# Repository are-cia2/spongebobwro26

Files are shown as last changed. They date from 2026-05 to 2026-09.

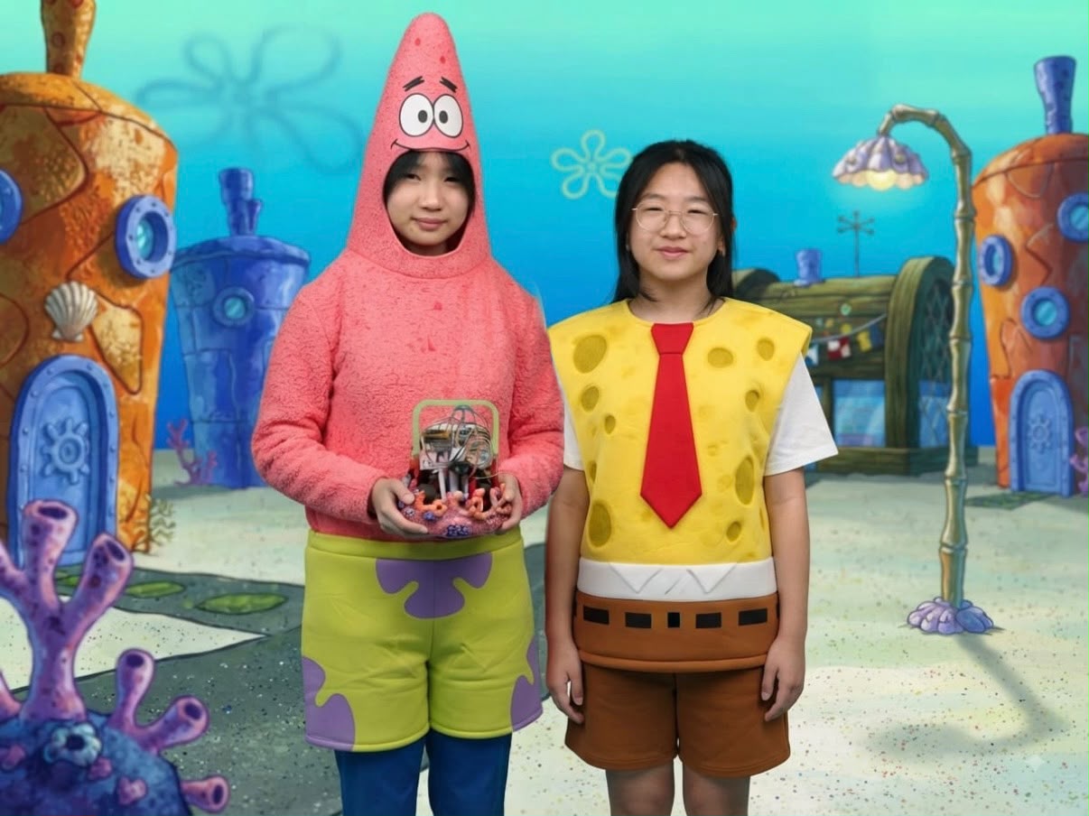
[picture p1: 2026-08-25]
t-photos/funnypic.jpeg

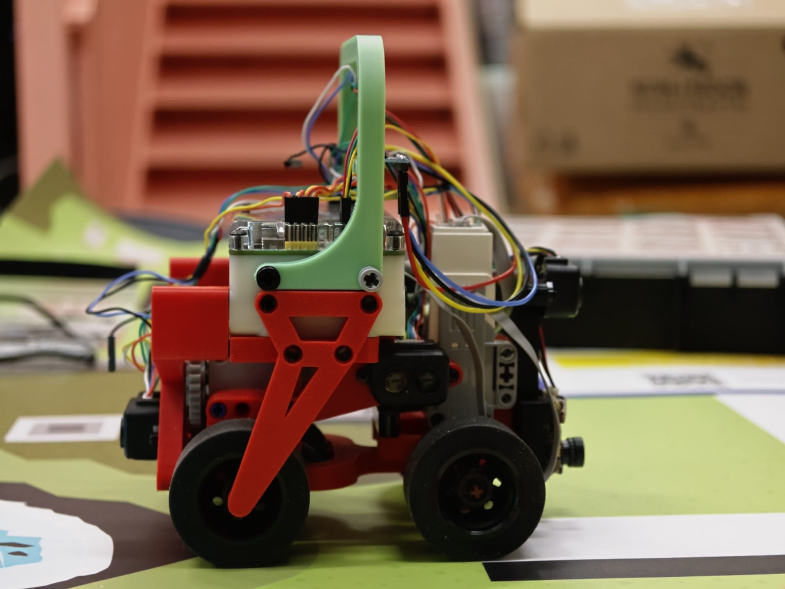
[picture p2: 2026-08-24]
v-photos/rightview.jpeg

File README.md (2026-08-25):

# CORE SPONGEBOB – WRO Future Engineers 2026

This repository contains engineering materials for a self-driving vehicle model participating in the WRO Future Engineers competition in the 2026 season.

## Team
WhatsApp Image 2026-08-23 at 12 37 10 PM

---

## Robot Overview
Our robot was designed with a custom 3D-printed chassis, Ackermann steering geometry, 

Our vehicle is a four-wheeled, car-like autonomous robot built around an EVN Alpha RP2040 controller, a mixed 3D-printed PLA/LEGO-compatible chassis and and a sensor suite optimised for wall tracking and obstacle navigation. One LEGO MINDSTORMS EV3 Medium Motor drives a mechanically linked axle through a gear train and differential. A second EV3 Medium Motor actuates a geared Ackermann steering linkage. The robot uses 40 mm silicone wheels. Four TF-Luna LiDAR sensors point forward, rearward, left, and right. An MPU6500 inertial measurement unit provides relative yaw through the I2Cdevlib Digital Motion Processor (DMP).

For both challenges, the vehicle follows a wall down each straight, detects the open side of each corner, turns to successive 90-degree headings, counts 12 corners as three laps, and brakes when the front and rear ranges indicate that it has returned to its starting section. The software runs sensing on one RP2040 core and navigation/motor control on the other.

## Robot Pictures

| Front View | Left View | Right View |
|---|---|---|
| Front View | Back View | Top View |

| Top View | Bottom View | Back View |
|---|---|---|
| Bottom View | Left View | Right View |

---

## Performance Videos
Open challenge: https://youtu.be/y6kY5s8JME0?si=EC7A0Hvez6JDP7O8

Obstacle challenge: https://youtu.be/tH5Cm9ztciE?si=E40YTndC0-gIS9aX

---

## Mobility & Mechanical Design

For this competition, we custom‑designed our chassis in Fusion 360 and manufactured components using FFF 3D printing with PLA. The platform integrates off‑the‑shelf electronics, including LEGO MINDSTORMS EV3 medium motors and a custom sensor suite: four TF‑Luna LiDAR sensors for ranging, an MPU6500 6‑DOF IMU for heading estimation, and an OpenMV Cam H7 (AE3) for visual navigation. Power is supplied by two 18650 cells in series, regulated through DRV8833 motor‑driver circuitry.

The vehicle combines:
- EVN ALPHA as the main single‑board microcontroller  
- LEGO MINDSTORMS EV3 medium motors for drive and steering  
- Four Benewake TF‑Luna time‑of‑flight sensors for left, right, front, and rear ranging  
- An MPU6500 IMU with DMP for yaw estimation  
- An OpenMV AE3 camera for red/green traffic‑sign detection  
- Two 18650 cells connected in series  
- DRV8833 motor‑driver circuitry  
- [Custom printed chassis, sensor mounts, motor mounts, steering linkage, braces, and gear components](https://github.com/are-cia2/spongebobwro26/tree/main/models)

### Chasis
We designed a custom 3D‑printed chassis instead of using modular building sets because the competition requires a compact steering vehicle with geometry that cannot be optimised using fixed modules. Autodesk Fusion 360 allowed us to integrate the chassis, mounts, gear interfaces, and steering linkage into one coordinated system. This ensured that every structural element was aligned with the drive and steering requirements. FFF printing with PLA reduced cost and enabled rapid iteration, allowing us to test three chassis prototypes before finalising the design.

The chassis features a narrow front profile and short wheelbase to maximise steering angle and reduce turning radius. The EVN ALPHA controller is secured in a cross‑braced mount, while the back frame supports the gear train and rear sensor. Side braces connect the rear wheel area to the controller mount to minimise flex and preserve alignment during high‑torque manoeuvres.

### Torque-Speed Trade-Off 
We explicitly calculated torque and speed trade‑offs by testing three gear ratios (1:1, 1:2, and 1:3). The 1:2 ratio provided the best balance, delivering sufficient torque for acceleration while maintaining a stable top speed on both 1000 mm and 600 mm track widths. Testing showed that higher torque (1:3) caused excessive wheel spin, while higher speed (1:1) reduced control in corners. Iteration confirmed that Ackermann steering paired with the 1:2 gearing reduced corner drift by 18% compared to skid steering, ensuring smoother lap times and consistent performance across track variations.

### Controller
**[EVN Alpha](https://github.com/are-cia2/spongebobwro26/blob/main/schemes/evnFrontpins.svg) (16 I2C channels, USB-C for code upload)**

We decided to make use of the EVN Alpha to control the robot. Compared to the LEGO Mindstorms EV3 and NXT controllers, the EVN Alpha has 64 holes on 5 sides of the controller, compared to 32 holes on 3 sides of the other controllers, making it much easier to mount other parts on the EVN Alpha. Furthermore, the EVN Alpha is also much more compact, allowing the robot’s movements to be much more precise and accurate. The EVN Alpha also features a USB-C Port that is used to charge the batteries and download code, which is much more convenient compared to the EV3 or other NXT Controllers. Lastly, this controller has a total of 16 I2C channels, which eliminates the 4-port constraint of other controllers like the EV3 brick. 

### Motors
**2 × LEGO EV3 Medium [Motors](https://github.com/are-cia2/spongebobwro26/blob/main/schemes/evnBackpins.svg) (drive + steering)**

Our robot uses 2 LEGO MINDSTORMS EV3 medium motors due to their lightweight, compact form factor, and high speed compared to EV3 large motors and NXT motors. 

*Drive Mechanism and Differential*

One LEGO MINDSTORMS EV3 Medium Motor drives the wheel axle through a multi-stage
gear train and a mechanical differential to transfer power to the desired wheel location while balancing speed and torque. The differential lets the inside and outside wheels rotate at different speeds in corners while remaining powered from one motor, which satisfies the WRO prohibition on independent differential drive. The vehicle rolls on four nominally 40 mm silicone wheels; their loaded diameter still needs a calliper measurement for the final distance calibration.

The current software contains this output-speed ratio:

```text
wheel revolutions / motor revolution = (40 / 24) / 1.4 / 1.67
                                     = approximately 0.713
```

This means the ideal torque multiplication is the reciprocal:

```text
ideal torque multiplication = 1 / 0.713 = approximately 1.403
```

To shorten the wheelbase as much as possible, the long medium motor is mounted directly above the main drive assembly. The drivetrain comprises three distinct reduction stages:
- First Stage (40:24): A big-to-small gear configuration directly from the medium motor designed to compact the motor placement and optimise the overall layout.
- Second Stage (20:28): A small-to-big setup driving the differential gear, using a 20-tooth bevel pinion gear to drive a 28-tooth crown wheel on the rotating cage, enabling right-angle torque transmission.
- Third Stage (12:20): A small-to-big stage providing the final speed reduction to the wheels. Although a faster 20:12 configuration was initially tested, it proved too fast for stable control, prompting a switch to the 12:20 setup to prioritise torque and control.

*Steering Mechanism*
The steering actuator is a LEGO MINDSTORMS EV3 Medium Motor on EVN motor port 3.
Encoder channels on GPIO 14 and 15 provide position feedback. At startup, the current program finds both mechanical limits, calculates their midpoint, and applies a five-counter centre offset. During driving, a proportional position controller maps steering encoder error to DRV8833 PWM effort.

```text
  targetPosition = constrain(targetPosition, rightAngle - 5, leftAngle + 5);
  int positionError = pulseCount - targetPosition;
  int pwmRun = constrain(positionError * 22, -255, 255);
```

The geared linkage uses Ackermann steering geometry so the inner wheel can turn
through a larger angle than the outer wheel. This reduces tire scrub compared
with parallel steering. Current scaled-setup trials suggest an approximately
150 mm turning radius, but this is an estimate rather than a dimensioned final
measurement.

### Sensors

**4 × [TF-Luna](https://github.com/are-cia2/spongebobwro26/blob/main/schemes/TFLunapins.jpeg) LiDAR (front, rear, left, right)**

This sensor is a Time of Flight (TOF) distance measurement sensor. We chose to use this sensor because it is able to measure object distance accurately by measuring how long the light takes to bounce back to the sensor. The code corrects line-of-sight range to estimated perpendicular wall distance:

$$
d_{perpendicular} = d_{raw}\cos(\Delta\psi)
$$
where $\Delta\psi$ is yaw relative to the nearest cardinal field heading. This
assumes a planar axis-aligned wall and is intentionally not trusted when a beam
looks through an open corner.
    
**1 x [MPU6050](https://github.com/are-cia2/spongebobwro26/blob/main/schemes/MPU6050pins.jpeg) IMU (yaw estimation)**

The IMU mount began as a carrying handle but was repurposed to hold the IMU level and away from motor heat, preserving sensor accuracy. The front sensor mount fixes the camera and forward LiDAR in a repeatable geometry, while side and rear LiDAR mounts elevate the sensors to reduce floor reflections and maintain clear views of the field walls. This placement strategy was iterated three times, with final mounting heights chosen to maximise detection reliability at the sensors’ 3‑meter range.

**1 × [OpenMV AE3 camera](https://github.com/are-cia2/spongebobwro26/blob/main/schemes/OpenMVae3pins.jpeg) (traffic sign detection)**

The OpenMV AE3 allows for a long-range vision strategy while significantly elevating performance. Equipped with dual hardware Neural Processing Units (NPUs) and a 1 MP colour global shutter sensor, the AE3 processes machine-learning detection models with minimal latency and captures crystal-clear frames without motion blur while driving. Combined with low power consumption and onboard Time-of-Flight ranging, the OpenMV AE3 is more than sufficient for rapidly classifying visual targets and enabling swift, accurate navigation decisions during dynamic runs.

#### Electrical Architecture and Wiring

```mermaid
flowchart TD
   BAT[2S Molicel P26A: 7.2 V nominal, 8.4 V full, 2.6 Ah] --> PROTECT[Fuse or protection: TBD]
    PROTECT --> SWITCH[Main power switch]
    SWITCH --> EVN[EVN Alpha]
    EVN --> M1[Motor port 1: drive motor]
    EVN --> M3[Motor port 3: steering motor]
    EVN --> MUX0[I2C mux bank Wire: ports 1-8]
    MUX0 --> P1[Port 1: MPU6500]
    MUX0 --> P2[Port 2: rear TF-Luna]
    MUX0 --> P3[Port 3: front TF-Luna]
    MUX0 --> P4[Port 4: left TF-Luna]
    MUX0 --> P5[Port 5: right TF-Luna]
```

### Power
**2 × 18650 cells in series (8.4 V max), regulators for 3.3 V and 5 V rails** 

They are connected in series to provide the EVN ALPHA with 8.4v and are rated for 4.2v when fully charged. The motors run off unregulated battery power, consuming up to 780mA each at stall. There are 2 on-board regulators. The 3.3v regulator powers most of the system and is able to supply 3A. The current consumption of our 3.3V peripherals is under 1A. The 5V regulator only supplies the 5V rail and provides up to 3A. The only sensors we have attached to the 5V rail are the 2 Benewake sensors. While ranging, each sensor draws up to 600mA in a short pulse. This means that we are also well within the current capabilities of the regulator. 

The cells we use are the Molicel P26A, featuring a maximum discharge current of 35A. At maximum load, our robot uses less than 2A with the maximum contribution from the 2 medium motors. With a rated capacity of 2.6Ah, it can easily last more than an hour of continuous operation.

---
## System Architecture

```mermaid
flowchart LR
    Battery[Battery and protection] --> Alpha[EVN Alpha RP2040]
    Alpha --> DriverA[Motor port 1 H-bridge]
    Alpha --> DriverS[Motor port 3 H-bridge]
    DriverA --> Drive[Medium drive motor]
    Drive --> Gearbox[Drive gear train]
    Gearbox --> Diff[Differential and drive axle]
    DriverS --> Steering[Medium steering motor]
    Steering --> SteerGear[Steering gear train and linkage]
    DriveEncoder[Drive encoder] --> Core0[Core 0: navigation and control]
    SteeringEncoder[Steering encoder] --> Core0
    StartButton[One start button] --> Core0
    MPU[MPU6500 yaw] --> Core1[Core 1: sensor service]
    Front[Front TF-Luna] --> Core1
    Rear[Rear TF-Luna] --> Core1
    Left[Left TF-Luna] --> Core1
    Right[Right TF-Luna] --> Core1
    Core1 -->|yaw, ranges, validity| Core0
    Core0 --> DriverA
    Core0 --> DriverS
```

The main subsystem interfaces are deliberately narrow. Core 1 is the only core that performs I2C transactions. It publishes scalar yaw and range values plus validity flags. Core 0 consumes those values, evaluates the navigation state machine, and drives both motors. This prevents motor timing from being coupled directly to slow I2C register reads and avoids simultaneous I2C use by both cores. 

## Code Structure

### Setup
The setup procedure is a calibration-and-initialisation routine: the code first configures the encoder interrupts for both steering channels, initialises the motor pins, and then sweeps the steering mechanism to find the left and right mechanical bounds. It records those positions as leftAngle and rightAngle, calculates the centre zeroPosition, and waits for the user button/input before starting the run. After that, it launches the sensor/IMU core (Core 1), allowing the main loop to use live yaw and distance data from the MPU and ToF sensors while continuously steering toward the required wall-tracking and turning states. In other words, the robot is first mechanically centred and calibrated, then the sensing system is started, and only after the IMU is valid does the state machine begin.

### Core 1 (Sensors)

```mermaid
stateDiagram-v2 
  [*] --> INITIALISE 
  INITIALISE --> CALIBRATE: calibration required 
  INITIALISE --> LOADOFFSETS: calibration saved 
  CALIBRATE --> IMU LOADOFFSETS --> IMU 
  IMU --> READSENSORS READSENSORS --> 
  READSENSORS: update yaw + distance sensors 
  READSENSORS --> CAMERA: Obstacle Challenge 
  CAMERA --> READSENSORS: colour detected / no colour 
  READSENSORS --> ROBOTCONTROL 
  ROBOTCONTROL --> READSENSORS
```

### [Open Challenge](https://github.com/are-cia2/spongebobwro26/tree/main/src/wro26open) State Machine

```mermaid
stateDiagram-v2
    [*] --> START
    START --> FIRSTWALL: yaw and four ranges ready
    FIRSTWALL --> BASICOVERSHOOT: front near and one side open
    BASICOVERSHOOT --> TURNRIGHT: CW entry distance reached
    BASICOVERSHOOT --> TURNLEFT: CCW entry distance reached
    TURNRIGHT --> FINDWALL: target 90-degree heading reached
    TURNLEFT --> FINDWALL: target 90-degree heading reached
    FINDWALL --> WALLTRACK: inside wall reacquired after delay
    WALLTRACK --> BASICOVERSHOOT: corner 1 through 11
    WALLTRACK --> OVERSHOOT: approach to corner 12
    OVERSHOOT --> TURNRIGHT: final CW entry reached
    OVERSHOOT --> TURNLEFT: final CCW entry reached
    TURNRIGHT --> LASTWALL: final turn complete
    TURNLEFT --> LASTWALL: final turn complete
    LASTWALL --> STOP: startup front/rear pose crossed
    STOP --> STOP
```

### [Obstacle](https://github.com/are-cia2/spongebobwro26/tree/main/src/wro26obstacle) Challenge State Machine

```mermaid
stateDiagram-v2 
  [*] --> START 
  START --> FIRSTWALL: sensors valid and starting wall selected 
  FIRSTWALL --> LEFTOBSTACLE: green obstacle detected
  FIRSTWALL --> RIGHTOBSTACLE: red obstacle detected FIRSTWALL --> STOP: front detected + corner direction identified 
  LEFTOBSTACLE --> FIRSTWALL: obstacle passed 
  RIGHTOBSTACLE --> FIRSTWALL: obstacle passed 
  FIRSTWALL --> BASICOVERSHOOT: corner detected 
  BASICOVERSHOOT --> TURNRIGHT: CW distance reached 
  BASICOVERSHOOT --> TURNLEFT: CCW distance reached 
  TURNRIGHT --> FINDWALL: 90-degree heading reached 
  TURNLEFT --> FINDWALL: 90-degree heading reached 
  FINDWALL --> RIGHTOBSTACLE: wall reacquired after delay 
  FINDWALL --> LEFTOBSTACLE: obstacle detected 
  RIGHTOBSTACLE --> FINDWALL: obstacle passed 
  LEFTOBSTACLE --> FINDWALL: obstacle passed 
  FINDWALL --> WALLTRACK: wall reacquired 
  WALLTRACK --> LEFTOBSTACLE: obstacle detected 
  WALLTRACK --> RIGHTOBSTACLE: obstacle detected 
  WALLTRACK --> BASICOVERSHOOT: normal corner detected 
  WALLTRACK --> OVERSHOOT: final corner detected 
  BASICOVERSHOOT --> TURNRIGHT: CW
  BASICOVERSHOOT --> TURNLEFT: CCW
  OVERSHOOT --> TURNRIGHT: final CW distance reached 
  OVERSHOOT --> TURNLEFT: final CCW distance reached 
  TURNRIGHT --> LASTWALL: final turn complete 
  TURNLEFT --> LASTWALL: final turn complete
  LASTWALL --> LEFTOBSTACLE: obstacle detected 
  LASTWALL --> RIGHTOBSTACLE: obstacle detected 
  LASTWALL --> STOP: starting position reached
  STOP --> STOP
```
#### [Obstacle Detection Camera Code](https://github.com/are-cia2/spongebobwro26/tree/main/src/wro2026camera) on OpenMV:

The obstacle detection uses the OpenMV AE3 camera to detect red and green blobs in each frame, threshold them by colour, and identify the largest matching blob. It then checks the blob’s orientation and size, and if a valid marker is seen for long enough (based on clock.fps()) and is large enough (height of blob > certain value), it sends a command over UART to the robot indicating whether the obstacle is on the left or right side, using messages like “a”, “b”, “c”, or “d” to signal left green, right green, left red, and right red respectively. This acts as the robot’s external obstacle-awareness layer, allowing the main code to react to colored markers by changing its state in the state machine.

## Testing and Tuning Methods

Our testing and tuning process focuses on changing one independent variable at a time while keeping the test layout and other conditions constant. This allows us to identify which changes actually improve the robot’s performance rather than attributing improvements to multiple changes at once. For each test, we record raw sensor and control data and use a predefined metric, such as completion time, positional accuracy, or number of contacts, to determine whether a change is an improvement. Constants are accepted only after being supported by a specific test record, rather than simply because they appeared to “work better.”

Testing is carried out on our scaled-down test setup, which has a 90 cm × 90 cm middle section and is reasonably close to the dimensions of the actual field. During recent testing, complete Open Challenge runs were observed in under 50 seconds in both clockwise and counter-clockwise directions. We also did not observe noticeable yaw drift or drive-distance errors during these runs. These results suggest that the current tuning is promising, but visual observation alone cannot confirm that the robot has zero error or that the results would be identical on the full regulation field.

To make our conclusions more reliable, further testing will involve recording the number of runs, individual completion times, contacts, finish outcomes, IMU data, and encoder distance compared with physical tape measurements. These records will allow us to calculate meaningful values such as average completion time, error bounds, yaw drift, and success rate. This provides a more systematic basis for selecting and justifying our final constants and ensures that our tuning decisions are supported by measurable evidence.

### Testing Results

| Run | Challenge Type | Direction | Completion Time (s) | Contacts | Heading Accuracy | End Distance from Start (cm) |
|-----|---|---|---|---|---|---|
| 1 | Open | CW | 43.2 | 0 | ±1° | 6 |
| 2 | Open | CCW | 44.1 | 0 | ±2° | 5 |
| 3 | Obstacle | CW | 52.4 | 0 | ±2° | 7 |
| 4 | Obstacle | CCW | 53.0 | 0 | ±1° | 4 |

**Average completion time (Open Challenge):** 49.4s  
**Average completion time (Obstacle Challenge):** 52.7s  
**Contacts:** 0 (all runs successful)  
**Heading accuracy:** consistently within ±2° tolerance  
**End distance from start:** within 5–7 cm (inside threshold)

## Bill of Materials (Core Components)

| Component | Qty | Price (USD) |
|---|-----|---|
| TF-Luna LiDAR | 4 | $27.05 ea |
| OpenMV AE3 Camera  | 1 | $65.00 |
| MPU6050 IMU | 1 | $2.94 |
| EVN Alpha | 1 | $128.00 |
| **Total** | | **$304.14** |

## Upload Process

1. **Code Development**
   - EVN Alpha code written in C++.
   - OpenMV IDE used for AE3 camera scripts written in MicroPython.
   - Fusion 360 for CAD → exported STL → 3D print.

2. **Compilation**
   - EVN Alpha: Code compiled and uploaded via USB-C.
   - OpenMV AE3: Scripts uploaded via OpenMV IDE via USB-C.

3. **Upload**
   - Connect EVN Alpha via USB-C.
   - Flash firmware and upload code using the provided toolchain.
   - Camera scripts deployed separately.
   - 
---

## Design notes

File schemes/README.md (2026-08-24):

Electromechanical diagrams
====

This directory contains several schematic diagrams of the electromechanical components, illustrating the electrical elements used in the vehicle and how they connect to each other.

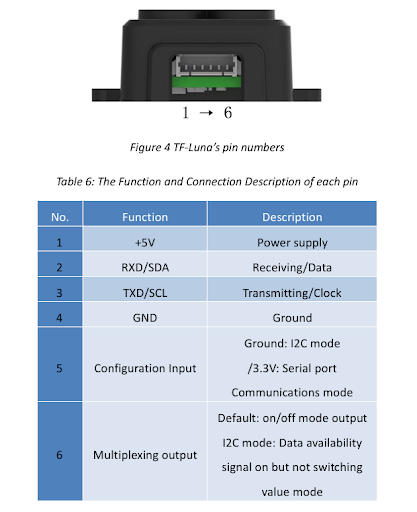
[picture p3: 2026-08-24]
schemes/TFLunapins.jpeg

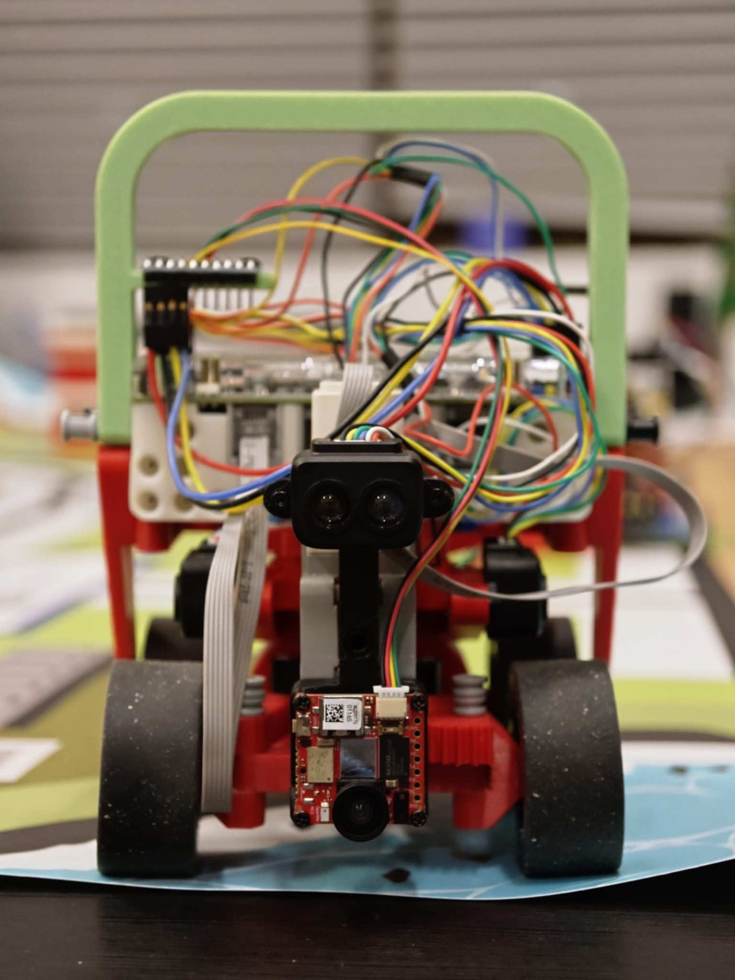
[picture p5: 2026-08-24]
v-photos/frontview.jpeg

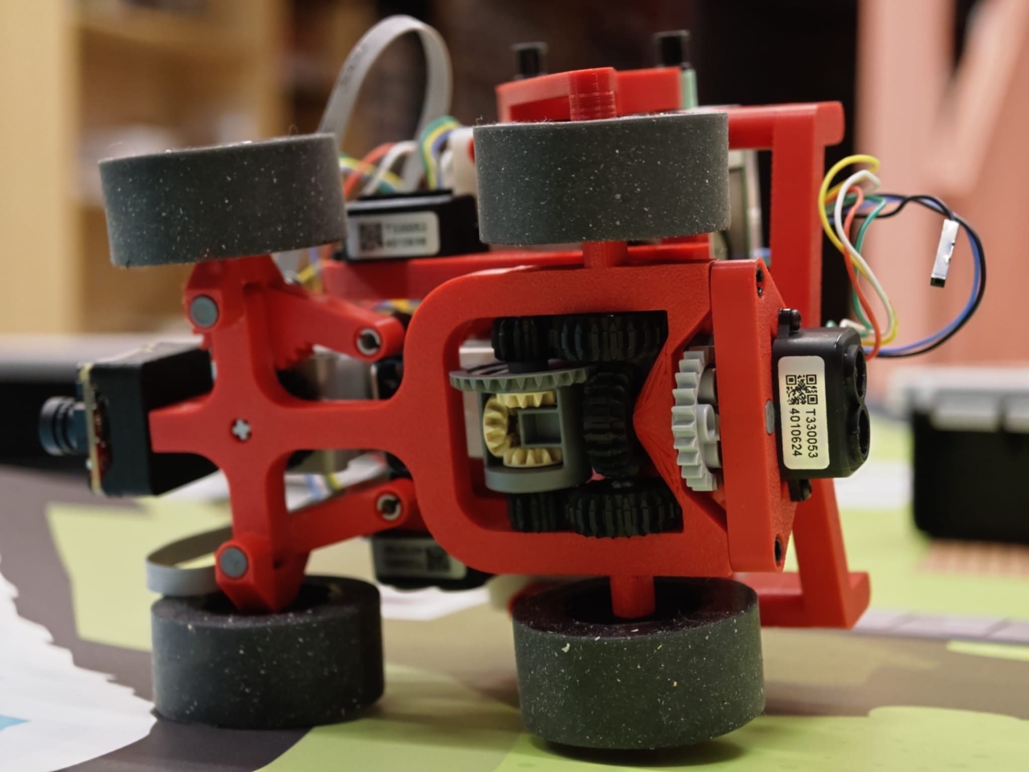
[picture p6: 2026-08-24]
v-photos/bottomview.jpeg

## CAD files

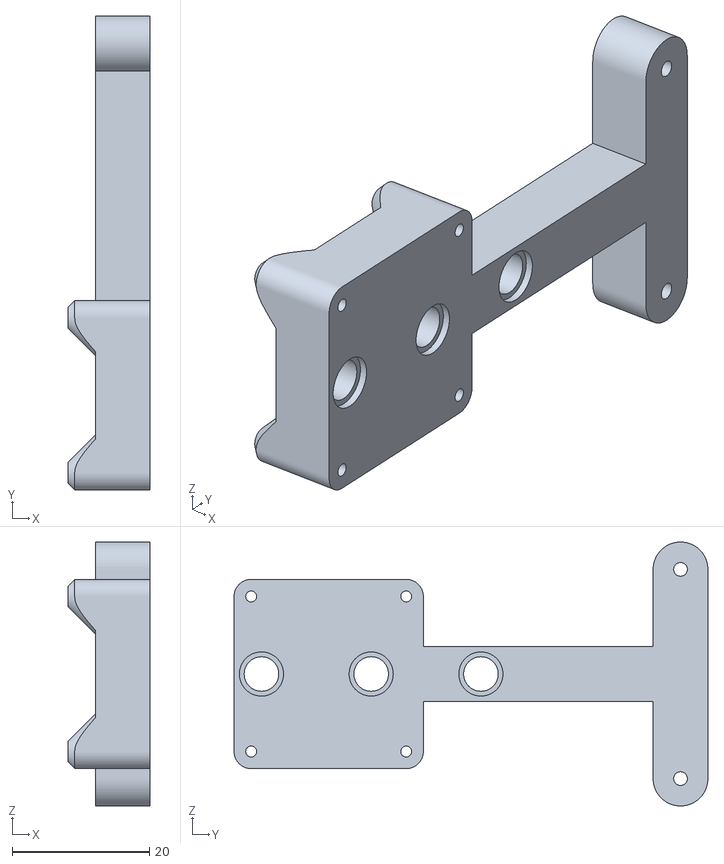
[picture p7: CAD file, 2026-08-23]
models/front mount.stl
12.0 x 69.1 x 38.5

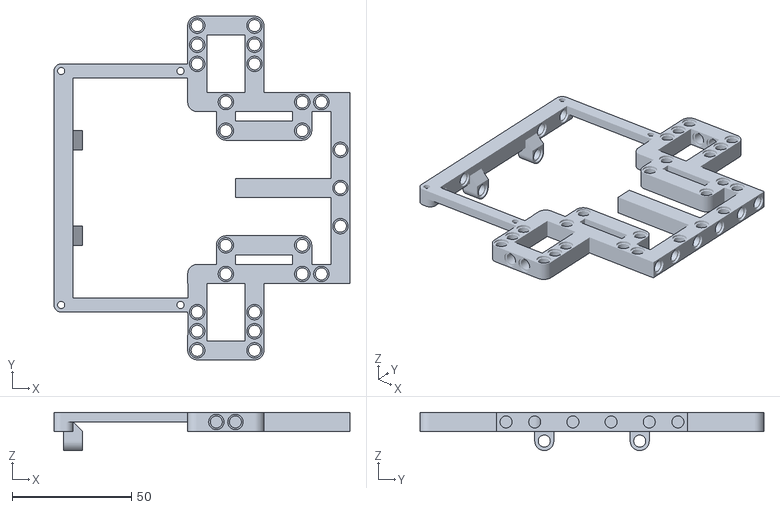
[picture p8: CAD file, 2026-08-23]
models/top frame.stl
124.0 x 144.0 x 16.0

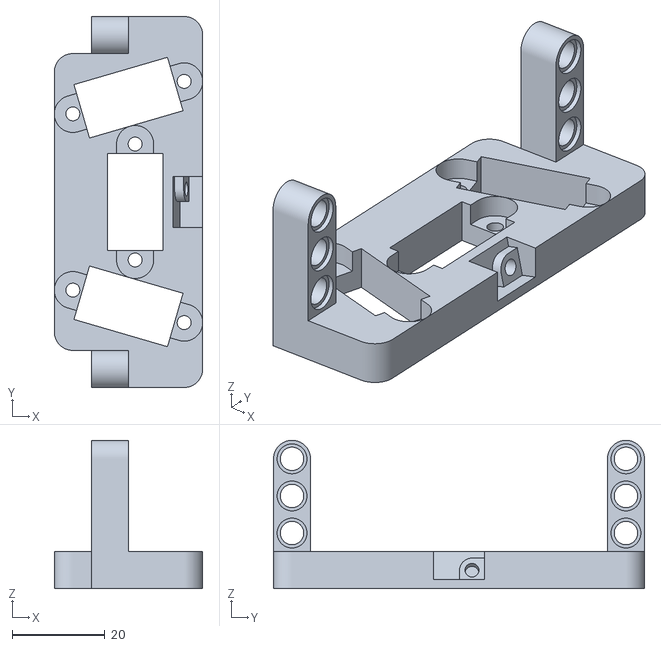
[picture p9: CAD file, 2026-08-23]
models/sensor plate.stl
32.0 x 80.0 x 32.0

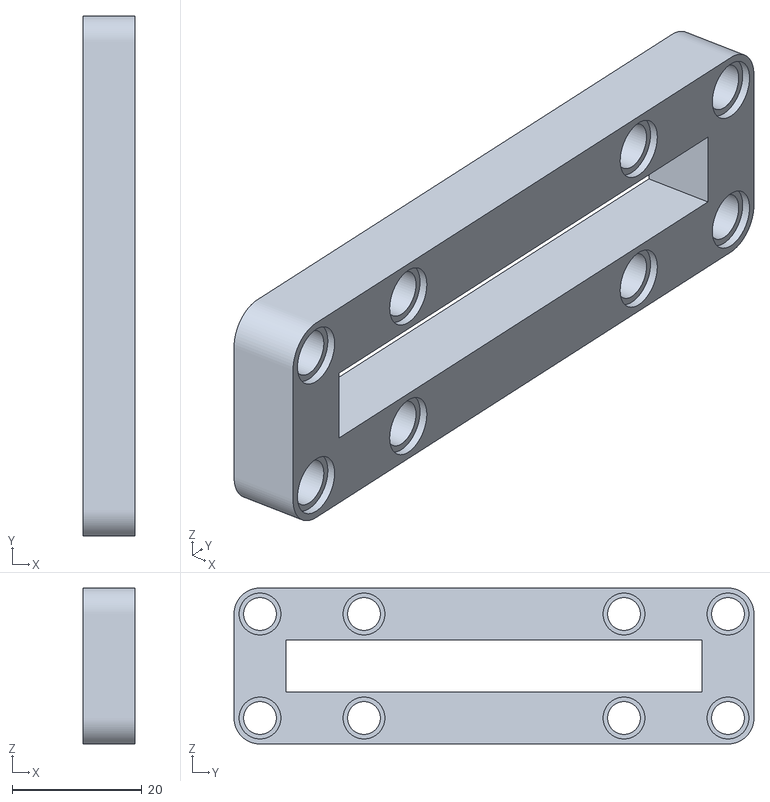
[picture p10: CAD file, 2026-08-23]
models/back frame.stl
8.00 x 80.0 x 24.0

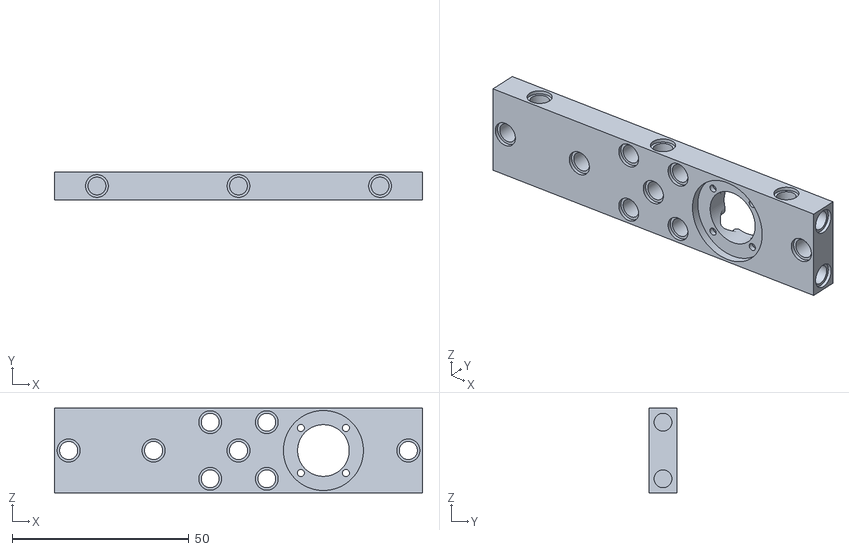
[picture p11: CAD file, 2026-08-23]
models/motor mount.stl
104.0 x 8.00 x 24.0

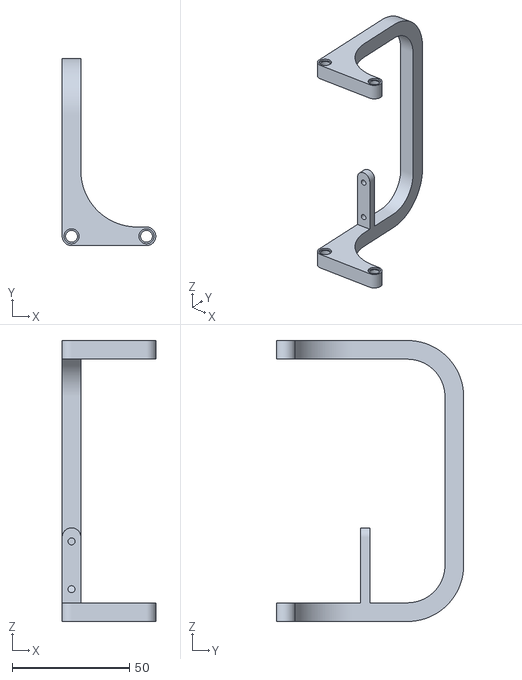
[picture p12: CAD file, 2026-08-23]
models/handle.stl
40.0 x 80.0 x 120.0

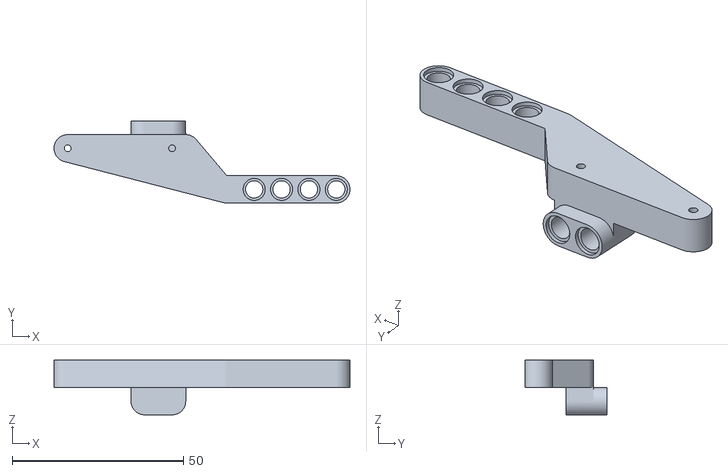
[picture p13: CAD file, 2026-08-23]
models/side sensor mount.stl
86.5 x 24.0 x 16.0

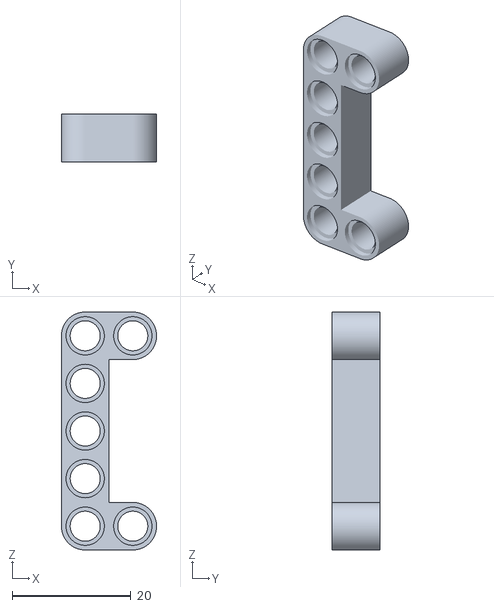
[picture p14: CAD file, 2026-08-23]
models/middle connecting piece.stl
16.0 x 8.00 x 40.0

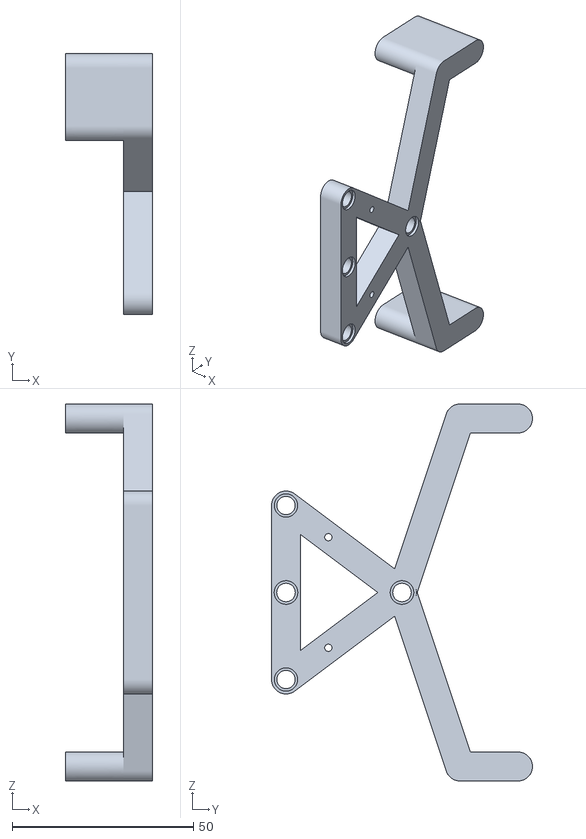
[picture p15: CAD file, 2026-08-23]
models/back brace.stl
24.0 x 72.0 x 104.0

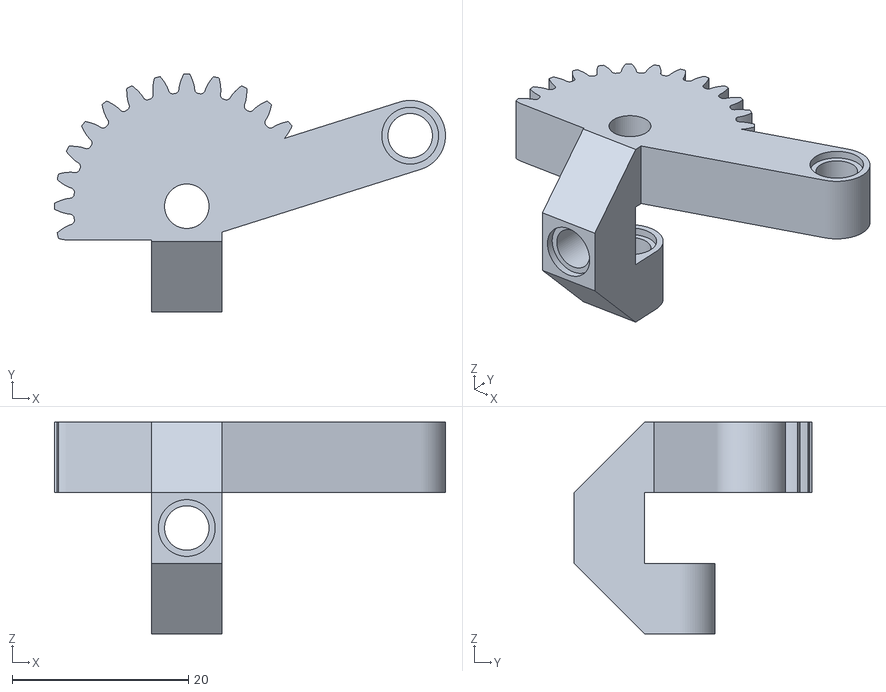
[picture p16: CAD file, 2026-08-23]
models/steering (mirror for sides).stl
44.3 x 27.0 x 24.0

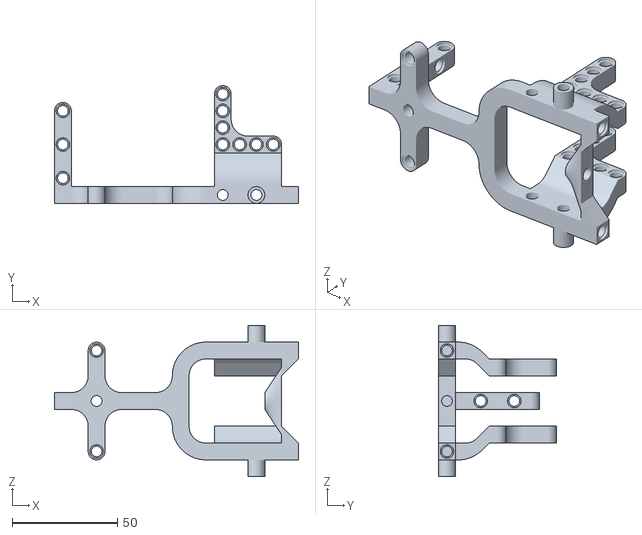
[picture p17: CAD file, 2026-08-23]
models/robot base.stl
116.0 x 56.0 x 72.0

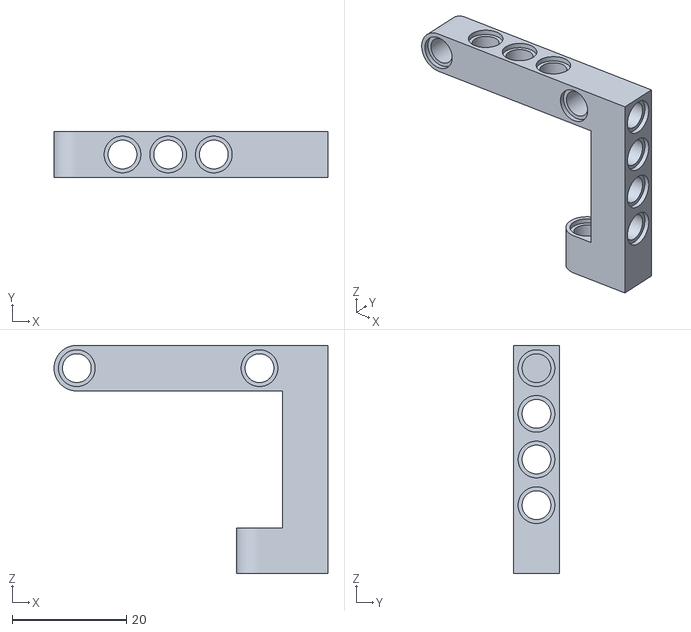
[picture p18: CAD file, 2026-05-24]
models/evn mount.stl
48.0 x 8.00 x 40.0

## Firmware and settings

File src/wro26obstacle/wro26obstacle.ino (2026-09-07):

#include <EVN.h>


#define START 0
#define FIRSTWALL 1
#define TURNLEFT 2
#define TURNRIGHT 3
#define WALLTRACK 4
#define STOP 5
#define PRINT 6
#define FINDWALL 7
#define LASTWALL 8
#define OVERSHOOT 9
#define LEFTOBSTACLE 10
#define RIGHTOBSTACLE 11
#define BASICOVERSHOOT 12
#define REVERSEBACK 13
#define SMALLLEFTTURN 14
#define SMALLRIGHTTURN 15
#define REVERSETURN 16

//to change
#define WALLTRACKDIST 41
#define FRONTTHRES 30
#define BACKTHRES 100
#define CORNERDETECT 88
#define WALLFOUND 60
#define BASICOVERSHOOTDIST 150
#define OVERSHOOTDIST 150
#define TURNTOLERANCE 3
#define DISTTOLERANCE 5
#define WALLAFTOBS 25
#define BIGTURNANGLE 80
#define SMALLTURNANGLE 52

char yippee;

float leftAngle;
float rightAngle;
float zeroPosition;
float leftStartDist;
float rightStartDist;
float frontStartDist;
float backStartDist;
float startDist;
float oriWallDist;
float obstacleDist;
unsigned long long initialTime;
volatile const float gearRatio = (((40.0 / 24.0) / 1.4) / 1.67);
extern volatile bool rangeDataReady;
float leftWallDist;
float rightWallDist;
float lastReverse = -999;

int var = START;
int prevvar = WALLTRACK;
int leftobstaclevar = 0;
int rightobstaclevar = 0;

bool cw = true;
bool startLeft = true;
bool lastturn = false;
int corner = 0;
int frontDistCounter = 0;
int obstacleTurnAngle = 52;
int wallCounter = 0;
int leftCounter = 0;
int rightCounter = 0;


extern volatile float stuffYaw;
extern volatile bool stuffValid;
extern volatile int leftDist;
extern volatile int checkRightDist;
extern volatile int rightDist;
extern volatile int frontDist;
extern volatile int backDist;
extern volatile int snappedHeading;
extern volatile bool lefterror;
extern volatile bool righterror;
extern volatile bool fronterror;
extern volatile bool backerror;

extern volatile bool leftGreen;
extern volatile bool rightGreen;
extern volatile bool leftRed;
extern volatile bool rightRed;

volatile int pulseCount;  // Rotation step count
int SIG_A = 0;            // Pin A output
int SIG_B = 0;            // Pin B output
int lastSIG_A = 0;        // Last state of SIG_A
int lastSIG_B = 0;        // Last state of SIG_B
const int Pin_A = 14;     // Interrupt pin (digital) for A (change your pins here)
const int Pin_B = 15;     // Interrupt pin (digital) for B

void A_CHANGE() {                                 // Interrupt Service Routine (ISR)
  detachInterrupt(digitalPinToInterrupt(Pin_A));  // Important
  SIG_A = digitalRead(Pin_A);                     // Read state of A
  SIG_B = digitalRead(Pin_B);                     // Read state of B

  if ((SIG_B == SIG_A) && (lastSIG_B != SIG_B)) {
    pulseCount--;  // Counter-clockwise rotation
    lastSIG_B = SIG_B;
  }

  else if ((SIG_B != SIG_A) && (lastSIG_B == SIG_B)) {
    pulseCount++;                   // Clockwise rotation
    lastSIG_B = SIG_B > 0 ? 0 : 1;  // Save last state of B
  }
  attachInterrupt(digitalPinToInterrupt(Pin_A), A_CHANGE, CHANGE);
}


volatile int pulseCountback;  // Rotation step count
volatile int initialpulseCountback;
int SIG_Aback = 0;         // Pin A output
int SIG_Bback = 0;         // Pin B output
int lastSIG_Aback = 0;     // Last state of SIG_A
int lastSIG_Bback = 0;     // Last state of SIG_B
const int Pin_Aback = 19;  // Interrupt pin (digital) for A (change your pins here)
const int Pin_Bback = 18;  // Interrupt pin (digital) for B

void A_CHANGEBACK() {                                 // Interrupt Service Routine (ISR)
  detachInterrupt(digitalPinToInterrupt(Pin_Aback));  // Important
  SIG_Aback = digitalRead(Pin_Aback);                 // Read state of A
  SIG_Bback = digitalRead(Pin_Bback);                 // Read state of B

  if ((SIG_Bback == SIG_Aback) && (lastSIG_Bback != SIG_Bback)) {
    pulseCountback--;  // Counter-clockwise rotation
    lastSIG_Bback = SIG_Bback;
  }

  else if ((SIG_Bback != SIG_Aback) && (lastSIG_Bback == SIG_Bback)) {
    pulseCountback++;                       // Clockwise rotation
    lastSIG_Bback = SIG_Bback > 0 ? 0 : 1;  // Save last state of B
  }
  attachInterrupt(digitalPinToInterrupt(Pin_Aback), A_CHANGEBACK, CHANGE);
}


void runPosition(int targetPosition) {
  targetPosition = constrain(targetPosition, rightAngle - 5, leftAngle + 5);
  int positionError = pulseCount - targetPosition;  //(headingError * 5.0) - (steer.getPosition() - STEER_CENTER);
  //Serial.println(positionError);
  int pwmRun = constrain(positionError * 22, -255, 255);
  //Serial.println(pwmRun);
  if (positionError > 0) {
    // turn cw
    digitalWrite(23, HIGH);
    analogWrite(22, 255 - pwmRun);
  } else {
    //turn ccw
    digitalWrite(22, HIGH);
    analogWrite(23, 255 + pwmRun);
  }
}

volatile bool core0_ready = false;
volatile bool core1_ready = false;
int steerRightBound = 0;
int steerLeftBound = 0;

int steerOffset = 5;

void setup() {
  Serial2.begin(115200);

  SIG_Bback = digitalRead(Pin_Bback);  // Current state of B
  SIG_Aback = SIG_Bback > 0 ? 0 : 1;   // Let them be different
  // Attach iterrupt for state change, not rising or falling edges
  attachInterrupt(digitalPinToInterrupt(Pin_Aback), A_CHANGEBACK, CHANGE);

  pinMode(28, OUTPUT);
  pinMode(29, OUTPUT);  // M1

  SIG_B = digitalRead(Pin_B);  // Current state of B
  SIG_A = SIG_B > 0 ? 0 : 1;   // Let them be different
  // Attach iterrupt for state change, not rising or falling edges
  attachInterrupt(digitalPinToInterrupt(Pin_A), A_CHANGE, CHANGE);

  pinMode(23, OUTPUT);
  pinMode(22, OUTPUT);  //M3
  digitalWrite(22, LOW);
  digitalWrite(23, HIGH);
  delay(1000);
  int currPosition = 0;
  int prevPosition = 999;
  while (true) {
    currPosition = pulseCount;
    if (currPosition == prevPosition) {
      break;
    }
    prevPosition = currPosition;
  }
  steerRightBound = pulseCount;
  digitalWrite(23, LOW);

  pinMode(LED_BUILTIN, OUTPUT);
  digitalWrite(LED_BUILTIN, LOW);

  pinMode(24, INPUT_PULLUP);

  digitalWrite(LED_BUILTIN, HIGH);

  unsigned long long initialTime = millis();

  while (millis() - initialTime <= 1000) {
    digitalWrite(22, HIGH);
    analogWrite(23, 0);
  }
  leftAngle = pulseCount;

  while (millis() - initialTime <= 2000) {
    digitalWrite(23, HIGH);
    analogWrite(22, 0);
  }
  rightAngle = pulseCount;


  //delay(1000);

  Serial.print(leftAngle);
  Serial.print("\t");
  Serial.println(rightAngle);
  Serial.println((leftAngle + rightAngle) / 2);
  zeroPosition = ((leftAngle + rightAngle) / 2) - steerOffset;

  Serial.println(gearRatio);

  while (!digitalReadFast(24)) runPosition(zeroPosition);
  while (digitalReadFast(24)) runPosition(zeroPosition);


  Serial.println("Starting");
  //Serial.println(stuffYaw);

  core0_ready = true;

  while (!core1_ready)
    ;
}

float getError(float angle) {

  //float targetAngle = initialAngle + angle;

  while (angle >= 180) {
    angle = angle - 360;
  }

  while (angle <= -180) {
    angle = 360 + angle;
  }

  float error = angle - stuffYaw;
  while (error >= 180) {
    error = error - 360;
  }

  while (error <= -180) {
    error = 360 + error;
  }

  //Serial.println(error);

  return error;
}

int turningAngle() {
  int angle = corner * 90;
  while (angle >= 180) {
    angle = angle - 360;
  }

  while (angle <= -180) {
    angle = 360 + angle;
  }


  return angle;
}

int miniLeftAngle() {
  int angle = 0;
  if (cw) {
    angle = turningAngle() - obstacleTurnAngle;
  } else {
    angle = turningAngle() + obstacleTurnAngle;
  }

  while (angle >= 180) {
    angle = angle - 360;
  }

  while (angle <= -180) {
    angle = 360 + angle;
  }


  return angle;
}

int miniRightAngle() {
  int angle = 0;
  if (cw) {
    angle = turningAngle() + obstacleTurnAngle;
  } else {
    angle = turningAngle() - obstacleTurnAngle;
  }
  while (angle >= 180) {
    angle = angle - 360;
  }

  while (angle <= -180) {
    angle = 360 + angle;
  }


  return angle;
}


void leftWallTrack(int distance, int baseAngle) {


  if (leftDist > 900 || leftDist == 0 || lefterror) {
    Serial.println("trackheading");
    trackHeading(baseAngle);

  } else {
    if (righterror || fronterror || backerror) {
      analogWrite(28, 50);
      digitalWrite(29, HIGH);
    } else {
      digitalWrite(28, LOW);
      digitalWrite(29, HIGH);
    }

    float leftError = distance - leftDist;
    float targetAngle = constrain(leftError * 5, -15, 15) + baseAngle;


    runPosition(zeroPosition - getError(targetAngle));
  }
}

void rightWallTrack(int distance, int baseAngle) {
  //Serial.println("rightwalltrack");

  if (rightDist > 900 || rightDist == 0 || righterror) {
    trackHeading(baseAngle);

  } else {
    if (lefterror || fronterror || backerror) {
      analogWrite(28, 50);
      digitalWrite(29, HIGH);
    } else {
      digitalWrite(28, LOW);
      digitalWrite(29, HIGH);
    }
    digitalWrite(28, LOW);
    digitalWrite(29, HIGH);
    float rightError = rightDist - distance;
    float targetAngle = constrain(rightError * 5, -15, 15) + baseAngle;

    runPosition(zeroPosition - getError(targetAngle));
  }
}

void bothWallTrack(int baseAngle) {


  if (leftDist == 0 || lefterror || rightDist == 0 || righterror) {
    Serial.println("trackheading");
    trackHeading(baseAngle);

  } else {
    if (fronterror || backerror) {
      analogWrite(28, 50);
      digitalWrite(29, HIGH);
    } else {
      digitalWrite(28, LOW);
      digitalWrite(29, HIGH);
    }
    float wallError = rightDist - leftDist;
    float targetAngle = constrain(wallError * 2, -15, 15) + baseAngle;

    runPosition(zeroPosition - getError(targetAngle));
  }
}



void trackHeading(int angle) {
  if (righterror || fronterror || backerror || lefterror) {
      analogWrite(28, 50);
      digitalWrite(29, HIGH);
    } else {
      digitalWrite(28, LOW);
      digitalWrite(29, HIGH);
    }
  float angleError = getError(angle);
  //Serial.println(angleError);
  runPosition(zeroPosition - angleError);
}

void reverseHeading(int angle) {
  digitalWrite(28, HIGH);
  digitalWrite(29, LOW);
  float angleError = -(getError(angle));
  runPosition(zeroPosition - angleError);
}

void loop() {

  if (Serial2.available()) {
    char yippee = Serial2.read();
    Serial.println(yippee);

    if (yippee == 'a') {  //leftgreen
      leftGreen = true;
      rightGreen = false;
      leftRed = false;
      rightRed = false;

    } else if (yippee == 'b') {  //rightgreen
      leftGreen = false;
      rightGreen = true;
      leftRed = false;
      rightRed = false;

    } else if (yippee == 'c') {  //leftRed
      leftGreen = false;
      rightGreen = false;
      leftRed = true;
      rightRed = false;

    } else if (yippee == 'd') {  //rightRed
      leftGreen = false;
      rightGreen = false;
      leftRed = false;
      rightRed = true;
    }
  }

  //Serial.println(var);
  switch (var) {
    case PRINT:
      Serial.print(leftDist);
      Serial.print("\t");
      Serial.println(rightDist);
      break;

    case START:

      while (!stuffValid || !rangeDataReady) {
        runPosition(zeroPosition);
      }
      Serial.println("START");

      corner = 0;
      leftStartDist = leftDist;
      rightStartDist = rightDist;
      frontStartDist = frontDist;
      backStartDist = backDist;
      var = WALLTRACK;

      break;

    case WALLTRACK:

      if (leftGreen) {
        prevvar = WALLTRACK;
        obstacleTurnAngle = BIGTURNANGLE;
        oriWallDist = rightDist;
        var = LEFTOBSTACLE;
        Serial.println("leftgreen");

      } else if (rightGreen) {
        prevvar = WALLTRACK;
        obstacleTurnAngle = SMALLTURNANGLE;
        oriWallDist = rightDist;
        var = LEFTOBSTACLE;
        Serial.println("rightgreen");

      } else if (leftRed) {
        prevvar = WALLTRACK;
        obstacleTurnAngle = SMALLTURNANGLE;
        oriWallDist = leftDist;
        var = RIGHTOBSTACLE;
        Serial.println("leftred");

      } else if (rightRed) {
        prevvar = WALLTRACK;
        obstacleTurnAngle = BIGTURNANGLE;
        oriWallDist = leftDist;
        var = RIGHTOBSTACLE;
        Serial.println("rightred");
      }

      if (!lefterror && !righterror) {
        if (cw) {

          if (leftDist < CORNERDETECT && rightDist < CORNERDETECT) {
            //Serial.println("bothwall");
            bothWallTrack(turningAngle());

          } else if (leftDist < rightDist) {
            rightCounter++;
            //Serial.println("leftwall");
            leftWallTrack(WALLTRACKDIST, turningAngle());

          } else if (corner == 0) {
            leftCounter++;
            trackHeading(0);
          }

        } else {
          if (leftDist < CORNERDETECT && rightDist < CORNERDETECT) {
            //Serial.println("bothwall");
            bothWallTrack(-turningAngle());

          } else if (leftDist > rightDist) {
            leftCounter++;
            //Serial.println("rightwall");
            rightWallTrack(WALLTRACKDIST, -turningAngle());
          }
        }

      } else if (!righterror && rightDist < CORNERDETECT) {
        //Serial.println("rightvalid");
        if (cw) {
          rightWallTrack(WALLTRACKDIST, turningAngle());
        } else {
          rightWallTrack(WALLTRACKDIST, -turningAngle());
        }


      } else if (!lefterror && leftDist < CORNERDETECT) {
        //Serial.println("leftvalid");
        if (cw) {
          leftWallTrack(WALLTRACKDIST, turningAngle());
        } else {
          leftWallTrack(WALLTRACKDIST, -turningAngle());
        }

      } else {
        //Serial.println("nonevalid");
        if (cw) {
          trackHeading(turningAngle());
        } else {
          trackHeading(-turningAngle());
        }
      }

      if (frontDist < FRONTTHRES && !fronterror && backDist > BACKTHRES && !backerror && millis() - lastReverse >= 1000 && leftDist + rightDist > 100) {
        corner++;

        digitalWrite(28, HIGH);
        digitalWrite(29, HIGH);

        unsigned long long initial = millis();

        while (millis() - initial <= 250 || leftCounter + rightCounter < 5) {
          if (!lefterror && leftDist > CORNERDETECT) {
            leftCounter++;
          }

          if (!righterror && rightDist > CORNERDETECT) {
            rightCounter++;
          }
        }

        if (leftCounter > rightCounter) {
          cw = false;

        } else {
          cw = true;
        }
        var = REVERSETURN;
      }


      break;

    case REVERSETURN:
      leftCounter = 0;
      rightCounter = 0;
      Serial.println("REVERSETURN");

      digitalWrite(28, HIGH);
      digitalWrite(29, LOW);

      if (cw) {
        runPosition(leftAngle);

        if (fabsf(getError(turningAngle())) < TURNTOLERANCE) {

          if (corner == 12) {
            var = LASTWALL;

          } else {
            digitalWrite(28, HIGH);
            digitalWrite(29, HIGH);
            delay(250);
            var = WALLTRACK;
          }
        }
      } else {
        runPosition(rightAngle);

        if (fabsf(getError(-turningAngle())) < TURNTOLERANCE) {
          if (corner == 12) {
            var = LASTWALL;

          } else {
            digitalWrite(28, HIGH);
            digitalWrite(29, HIGH);
            delay(250);

            var = WALLTRACK;
          }
        }
      }
      break;


    case LASTWALL:
      Serial.println("LASTWALL");

      if (cw) {
        leftWallTrack(leftStartDist, 0);
      } else {
        rightWallTrack(rightStartDist, 0);
      }

      if (frontDist <= frontStartDist + DISTTOLERANCE && backDist >= backStartDist - DISTTOLERANCE) {  //CHANGE TOLERANCE

        var = STOP;
      }

      break;

    case LEFTOBSTACLE:

      switch (leftobstaclevar) {

        case 0:  //turnleft
          Serial.println("left");
          Serial.print(stuffYaw);
          Serial.print("\t");
          Serial.println(-(miniLeftAngle()));

          digitalWrite(28, LOW);
          digitalWrite(29, HIGH);

          runPosition(leftAngle);

          if (cw) {
            if (abs(stuffYaw - miniLeftAngle()) < TURNTOLERANCE) {
              leftobstaclevar = 1;
            }
          } else {
            if (abs(stuffYaw + miniLeftAngle()) < TURNTOLERANCE) {
              leftobstaclevar = 1;
            }
          }

          break;

        case 1:  //turnright to front
          Serial.println("right");
          Serial.print(stuffYaw);
          Serial.print("\t");
          Serial.println(-(miniRightAngle()));

          digitalWrite(28, LOW);
          digitalWrite(29, HIGH);

          runPosition(rightAngle);

          if (cw) {
            if (abs(stuffYaw - turningAngle()) < TURNTOLERANCE) {
              leftobstaclevar = 2;
              wallCounter = 0;
              initialTime = millis();
            }
          } else {
            if (abs(stuffYaw + turningAngle()) < TURNTOLERANCE) {
              leftobstaclevar = 2;
              wallCounter = 0;
              initialTime = millis();
            }
          }

          break;

        case 2:  //find obstacle

          Serial.print(rightDist);
          Serial.print("\t");
          Serial.println(oriWallDist);
          Serial.println(wallCounter);

          trackHeading(turningAngle());

          if (rightDist < oriWallDist && !righterror) {
            wallCounter++;

            if (wallCounter >= 5) {
              obstacleDist = rightDist;
              wallCounter = 0;
              leftobstaclevar = 3;
            }
          }

          if (millis() - initialTime >= 250) {
            wallCounter = 0;
            leftobstaclevar = 4;
          }


          break;

        case 3:
          Serial.println(wallCounter);

          trackHeading(turningAngle());

          if (rightDist >= obstacleDist && !righterror) {
            wallCounter++;

            if (wallCounter >= 10) {
              wallCounter = 0;
              leftobstaclevar = 4;
            }
          }

          break;

        case 4:  //turn right
          digitalWrite(28, LOW);
          digitalWrite(29, HIGH);

          runPosition(rightAngle);

          if (cw) {
            if (abs(stuffYaw - miniRightAngle()) < TURNTOLERANCE) {
              leftobstaclevar = 5;
              wallCounter = 0;
            }
          } else {
            if (abs(stuffYaw + miniRightAngle()) < TURNTOLERANCE) {
              leftobstaclevar = 5;
              wallCounter = 0;
            }
          }

          break;


        case 5:  // turnleft to front
          Serial.println("front");
          Serial.print(stuffYaw);
          Serial.print("\t");
          Serial.println(-(turningAngle()));

          digitalWrite(28, LOW);
          digitalWrite(29, HIGH);

          runPosition(leftAngle);

          if (cw) {
            if (abs(stuffYaw - turningAngle()) < TURNTOLERANCE) {
              leftobstaclevar = 0;
              leftGreen = false;
              rightGreen = false;
              leftRed = false;
              rightRed = false;
              var = prevvar;
            }
          } else {
            if (abs(stuffYaw + turningAngle()) < TURNTOLERANCE) {
              leftobstaclevar = 0;
              leftGreen = false;
              rightGreen = false;
              leftRed = false;
              rightRed = false;
              var = prevvar;
            }
          }

          break;
      }

      break;

    case RIGHTOBSTACLE:

      switch (rightobstaclevar) {

        case 0:  //turnright
          Serial.println("right");
          /*
          Serial.print(stuffYaw);
          Serial.print("\t");
          Serial.println(miniRightAngle());
          */
          digitalWrite(28, LOW);
          digitalWrite(29, HIGH);

          runPosition(rightAngle);

          if (cw) {
            if (abs(stuffYaw - miniRightAngle()) < TURNTOLERANCE) {
              rightobstaclevar = 1;
            }
          } else {
            if (abs(stuffYaw + miniRightAngle()) < TURNTOLERANCE) {
              rightobstaclevar = 1;
            }
          }

          break;


        case 1:  //turnleft
          Serial.println("left");

          digitalWrite(28, LOW);
          digitalWrite(29, HIGH);

          runPosition(leftAngle);

          if (cw) {
            if (abs(stuffYaw - turningAngle()) < TURNTOLERANCE) {
              rightobstaclevar = 2;
              wallCounter = 0;
              initialTime = millis();
            }
          } else {
            if (abs(stuffYaw + turningAngle()) < TURNTOLERANCE) {
              rightobstaclevar = 2;
              wallCounter = 0;
              initialTime = millis();
            }
          }

          break;

        case 2:
          Serial.print(leftDist);
          Serial.print("\t");
          Serial.println(oriWallDist);
          Serial.println(wallCounter);

          trackHeading(turningAngle());

          if (leftDist < oriWallDist && !lefterror) {
            wallCounter++;

            if (wallCounter >= 5) {
              obstacleDist = leftDist;
              wallCounter = 0;
              rightobstaclevar = 3;
            }
          }

          if (millis() - initialTime >= 500) {
            wallCounter = 0;
            rightobstaclevar = 4;
          }


          break;

        case 3:
          Serial.println(wallCounter);

          trackHeading(turningAngle());

          if (leftDist >= obstacleDist && !lefterror) {
            wallCounter++;

            if (wallCounter >= 10) {
              wallCounter = 0;
              rightobstaclevar = 4;
            }
          }

          break;

        case 4:  //turn left
          digitalWrite(28, LOW);
          digitalWrite(29, HIGH);

          runPosition(leftAngle);

          if (cw) {
            if (abs(stuffYaw - miniLeftAngle()) < TURNTOLERANCE) {
              rightobstaclevar = 5;
              wallCounter = 0;
            }
          } else {
            if (abs(stuffYaw + miniLeftAngle()) < TURNTOLERANCE) {
              rightobstaclevar = 5;
              wallCounter = 0;
            }
          }

          break;
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

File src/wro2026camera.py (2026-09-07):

import csi
import time
import math
from machine import UART
from machine import LED

led_blue = LED("LED_BLUE")
led_blue.on()


# 1. Initialize UART Communications
uart = UART(1, 115200, timeout_char=200)

# 2. Color Threshold Arrays (LAB Color Space)
threshold_green = [(9, 27, -128, -9, -128, 127)]
threshold_red = [(21, 38, 13, 127, -128, 127)]

# 3. OpenMV v5.0.0+ CSI Camera Initialization Engine
csi0 = csi.CSI()
csi0.reset()
csi0.pixformat(csi.RGB565)
csi0.framesize(csi.QVGA)
csi0.snapshot(time=500)

# 4. Strict Manual Sensor Control Overrides
csi0.auto_gain(False, gain_db=24.082400)
csi0.snapshot(time=500)

csi0.auto_whitebal(False, rgb_gain_db=((1.604295, 0.0, 7.31645)))
csi0.snapshot(time=500)

csi0.auto_exposure(False, exposure_us=int(16648))
csi0.snapshot(time=500)

csi0.vflip(True)
csi0.hmirror(True)

# 5. Runtime Tracking Variables
clock = time.clock()
greenCounter = 0
redCounter = 0
redFound = False
greenFound = False

# 6. Global LED Definitions (Avoids inner loop memory allocation)
led_red = LED("LED_RED")
led_green = LED("LED_GREEN")
led_blue.off()

# 7. Front-filtering Settings (Targeting vertical objects at 90° with a 20° buffer)
TARGET_ROTATION = math.radians(90)
ROTATION_TOLERANCE = math.radians(20)

# Target Horizon Track Line set to 107
HORIZON_Y = 107

# 8. Main Execution Loop
while True:
    clock.tick()

    img = csi0.snapshot()

    # 🛠️ FIXED: Coordinates bundled into a tuple mapping (x0, y0, x1, y1)
    # img.draw_line((0, HORIZON_Y, img.width(), HORIZON_Y), color=(255, 255, 255), thickness=1)

    # Detect raw raw blobs via v5.0.0 API
    rawRedBlobs = img.find_blobs(threshold_red, pixels_threshold=250, area_threshold=250, merge=True)
    rawGreenBlobs = img.find_blobs(threshold_green, pixels_threshold=500, area_threshold=500, merge=True)

    # FRONT-FILTER: Ensure target blobs are vertical AND crossing the Y=107 horizon boundary
    # (b.y is the top boundary, and b.y + b.h is the bottom boundary)
    redBlobs = [
        b for b in rawRedBlobs
        if abs(b.rotation - TARGET_ROTATION) < ROTATION_TOLERANCE
        and b.y <= HORIZON_Y <= (b.y + b.h)
    ]

    greenBlobs = [
        b for b in rawGreenBlobs
        if abs(b.rotation - TARGET_ROTATION) < ROTATION_TOLERANCE
        and b.y <= HORIZON_Y <= (b.y + b.h)
    ]

    # Evaluate the largest qualified element based on the direct property .pixels
    largestRed = max(redBlobs, key=lambda b: b.pixels) if redBlobs else None
    largestGreen = max(greenBlobs, key=lambda b: b.pixels) if greenBlobs else None

    seenBlob = None
    blobColour = None

    if largestRed and largestGreen:
        if largestRed.pixels >= largestGreen.pixels:
            seenBlob = largestRed
            blobColour = "red"
        else:
            seenBlob = largestGreen
            blobColour = "green"
    elif largestRed:
        seenBlob = largestRed
        blobColour = "red"
    elif largestGreen:
        seenBlob = largestGreen
        blobColour = "green"
    else:
        seenBlob = False
        redFound = False
        greenFound = False

    # 9. Control Tracking & Interlock Logic Setup
    if seenBlob:
        rect = seenBlob.rect
        img.draw_rectangle(rect)

        if blobColour == "red":
            greenFound = False
            redFound = True
            greenCounter = 0
            print("red", redCounter)
            redCounter += 1
            if redCounter > (clock.fps() * 0.5):
                led_green.off()
                led_blue.on()
                led_red.off()

                # Check bounding box height element explicitly (Index 3 of rect tuple)
                if rect[3] >= 85:
                    led_green.off()
                    led_blue.off()
                    led_red.on()
                    if seenBlob.cx < 140:
                        print("leftred")
                        uart.write("c")
                    else:
                        print("rightred")
                        uart.write("d")
        elif blobColour == "green":
            redFound = False
            greenFound = True
            redCounter = 0

            print("green", greenCounter)
            greenCounter += 1

            if greenCounter >= (clock.fps() * 0.5):
                led_green.off()
                led_blue.on()
                led_red.off()
                # Check bounding box height element explicitly (Index 3 of rect tuple)
                if rect[3] >= 85:
                    led_red.off()
                    led_blue.off()
                    led_green.on()
                    if seenBlob.cx < 140:
                        print("leftgreen")
                        uart.write("a")
                    else:
                        print("rightgreen")
                        uart.write("b")
    else:
        # Failsafe default tracking condition state
        led_green.off()
        led_blue.off()
        led_red.off()

    if not redFound:
        redCounter = 0
    if not greenFound:
        greenCounter = 0

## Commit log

2026-05-03 Rename IMG_6463.jpeg to wheel design
2026-05-17 Enhance README with sensor details and images
    Added detailed descriptions and images for TFLUNA and MPU6050 sensors, explaining their functionalities and advantages over other sensor types.
2026-05-17 changed total length
    [second design of robot base.stl]
2026-05-24 Add files via upload
    connecting evn to robot base
    [evn mount wro.stl]
2026-05-24 brace for back gears and connects to evn
    [back brace wro.stl]
2026-08-17 Revise README for clarity on vehicle design and components
    Updated the README to enhance clarity and detail about vehicle design, hardware overview, and power management. Improved descriptions of components and their functionalities.
2026-08-17 Revise sensor information and power consumption data
    Updated sensor descriptions and power consumption details in README.
2026-08-24 Rename wheel design to wheeldesign.jpeg
2026-08-25 Update README with controller and motor details
    Enhanced the README with detailed descriptions of the controller and motors used in the robot, including comparisons to other controllers and the rationale for their selection. Updated sections for c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
